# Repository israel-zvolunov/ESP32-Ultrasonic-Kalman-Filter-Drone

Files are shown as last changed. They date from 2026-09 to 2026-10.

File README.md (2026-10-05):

# Drone Altitude Estimation System 🛸
**An Independent Standalone Payload utilizing ESP32 and Linear Kalman Filtering**

Developed as a Final Graduation Project at **Ruppin Academic Center** (2026).
* **Authors:** Netzach Israel Zvolunov & Avishag Avraham
* **Advisor:** Mr. Uzi Chester

---

## 📌 Project Overview
This project presents a standalone, independent payload module designed for real-time quadcopter altitude tracking and safety alerts. To overcome the high-noise environment caused by mechanical vibrations and propeller downwash, the system implements a **Linear Kalman Filter (LKF)** modeled on Constant Velocity (CV) kinematics. 

The system reads dynamic time-of-flight measurements from an ultrasonic sensor (HC-SR04), compensates for mechanical ring-up time biases through linear interpolation calibration, and uses a VCSEL-based laser LiDAR (TF-Luna) as a temporary practical ground truth reference for performance evaluation.

## 🛠️ Key Features
* **Dual-Core Processing:** Implemented in C++ on an ESP32 MCU using FreeRTOS to decouple time-critical sensor sampling from Wi-Fi UDP telemetry transmission.
* **Robust Noise Rejection:** Real-time 30Hz Kalman filtering capable of ignoring sensor time-outs and extreme outliers.
* **Physics-Based Simulation & Telemetry:** Comprehensive MATLAB FDTD wave propagation modeling alongside a real-time UDP Ground Station tracking tool.
* **Hardware Alert System:** Local GPIO-driven physical red LED warning when dropping below a defined safety threshold (1.0m).

---

## 📐 System Architecture
Here is the systemic breakdown of information and electrical distribution paths:

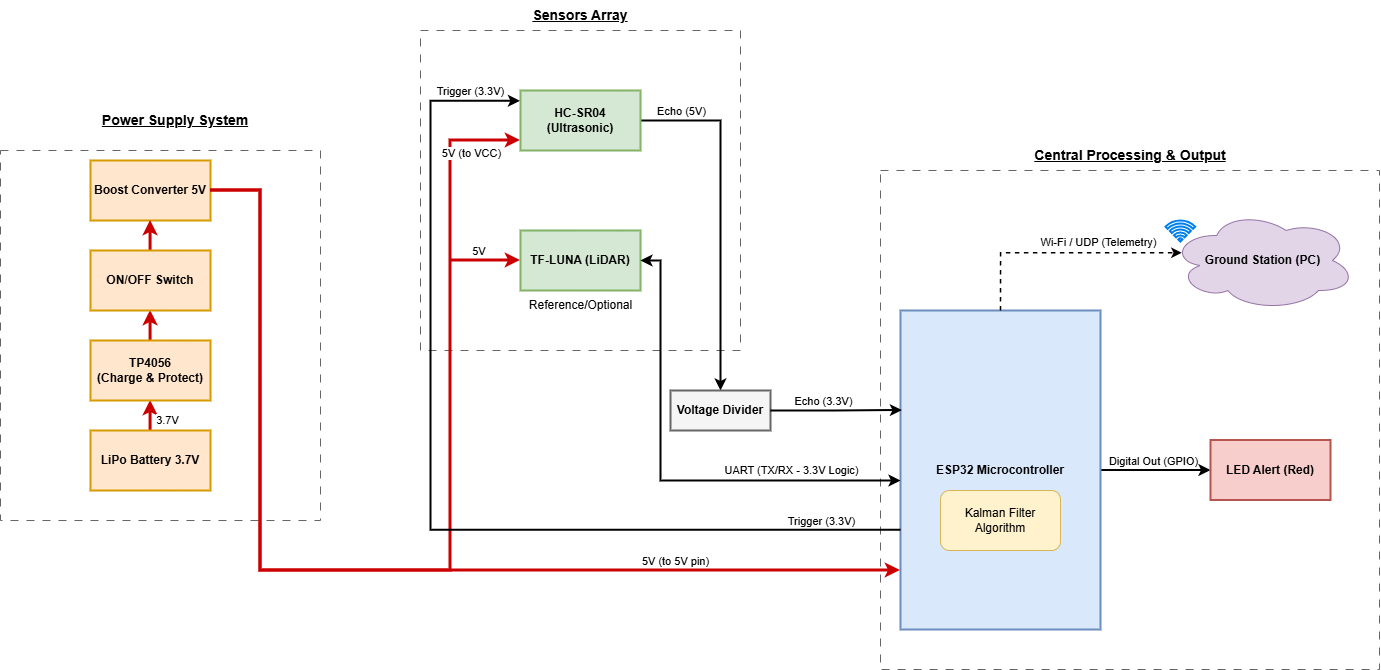
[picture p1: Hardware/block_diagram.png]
System Block Diagram


---

## 🔌 Hardware Wiring Diagram
The following layout represents the practical hardware integration, showcasing the custom independent power grid (LiPo 3.7V to 5V Boost) and the mcu protection voltage divider:

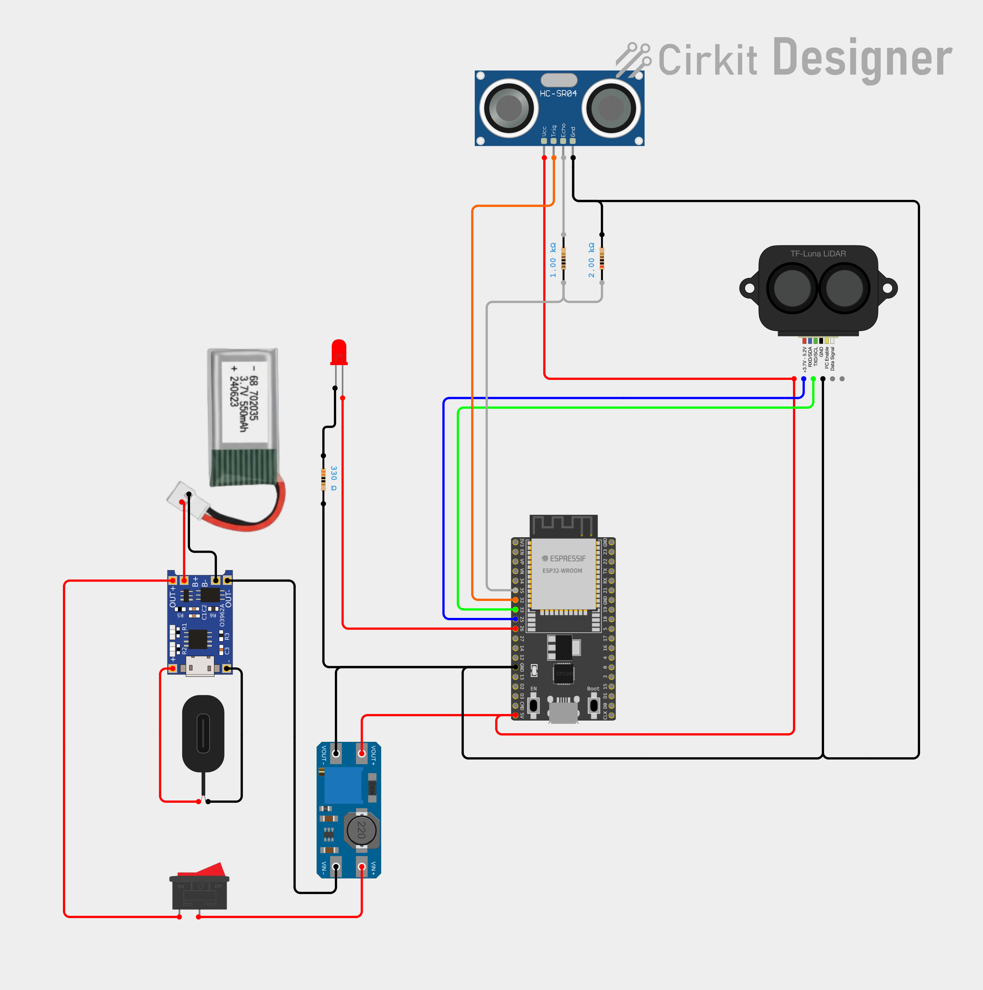
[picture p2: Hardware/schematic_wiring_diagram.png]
System Wiring Diagram


---

## 📐 Enclosure & Drone Integration
Custom standalone enclosure designed in Fusion 360 to securely house the payload components underneath the F450 quadcopter chassis while maintaining its center of gravity:

| 3D Enclosure View | Integrated Drone Payload |
| --- | --- |
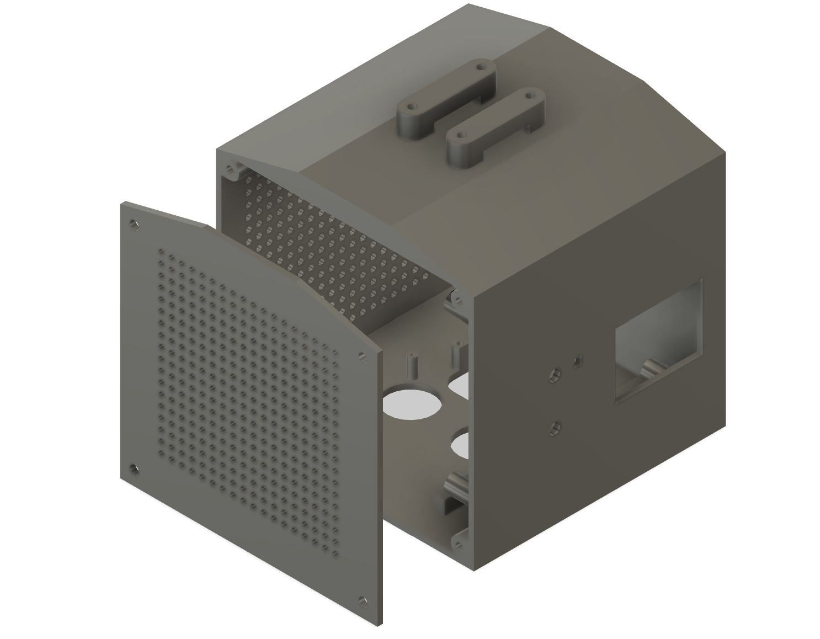
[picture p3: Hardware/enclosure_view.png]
Custom 3D-Printed Enclosure
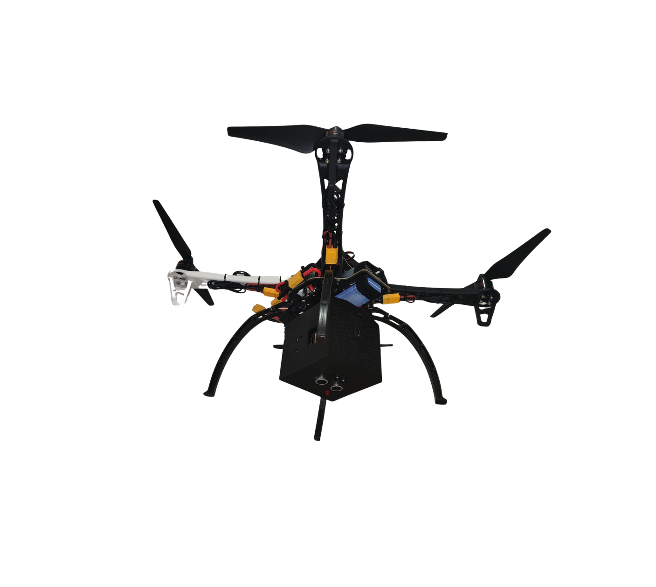
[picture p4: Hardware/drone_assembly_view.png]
Drone Assembly View
|  |  |

---

## 📁 Repository Directory Structure
* `/Firmware` : Contains the production C++ code (`esp32_ultrasonic_kalman_telemetry.ino`) for the ESP32 microcontroller, utilizing hardware interrupts and non-blocking timers.
* `/Simulation` : Complete MATLAB physics and mathematical modeling files:
  * `acoustic_wave_fdtd_simulation.m` — 1D FDTD acoustic propagation.
  * `kalman_filter_model_comparison_gui_exported.m` — Object-Oriented MATLAB App Designer dashboard comparing CV and CA models.
  * `kalman_filter_model_comparison_gui.mlapp` — App Designer binary file for direct layout editing in MATLAB.
* `/GroundStation` : Live diagnostic and telemetry tools running on the ground PC:
  * `ground_station_telemetry_dashboard.m` — Real-time 30Hz UDP telemetry receiver and absolute error plotter.
* `/Hardware` : Contains the Cirkit Designer wiring layout, enclosure image, and production-ready 3D files designed in Fusion 360:
  * `Drone_Box_Body.3mf` — Main chassis.
  * `Drone_Box_Lid.3mf` — Secure interlocking cover.
  * `schematic_wiring_diagram.png` — Real-world wiring schematic.
    * `enclosure_view.png` — Image of the 3D enclosure box.
  * `drone_assembly_view.png` — Photo of the payload integrated onto the F450 drone.

---

## 📊 Quick Start & Telemetry Activation
1. **Hardware Setup:** Connect the HC-SR04 through a 1kΩ/2kΩ voltage divider to GPIO35 (Echo) and GPIO32 (Trigger). Wire the TF-Luna to UART2 (GPIO33/25).
2. **Firmware Deployment:** Flash the ESP32 core via Arduino IDE using the `esp32_ultrasonic_kalman_telemetry.ino` file. Ensure the calibrated measurement noise covariance R = 0.000396 and process noise variance \(\sigma_a^2 = 3.36\) are properly defined in the configuration.
3. **Ground Station Telemetry:** Open MATLAB, run `ground_station_telemetry_dashboard.m` from the `/GroundStation` folder, and connect to the ESP32's local Access Point port via UDP to monitor real-time tracking.

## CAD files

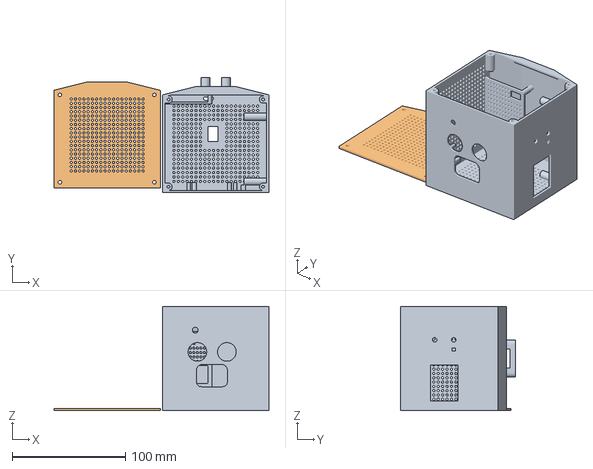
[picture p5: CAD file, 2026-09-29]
Hardware/Drone_Box_Body.3mf
190.0 x 102.0 x 92.0 mm
plastic_box
Drone_Box_Lid

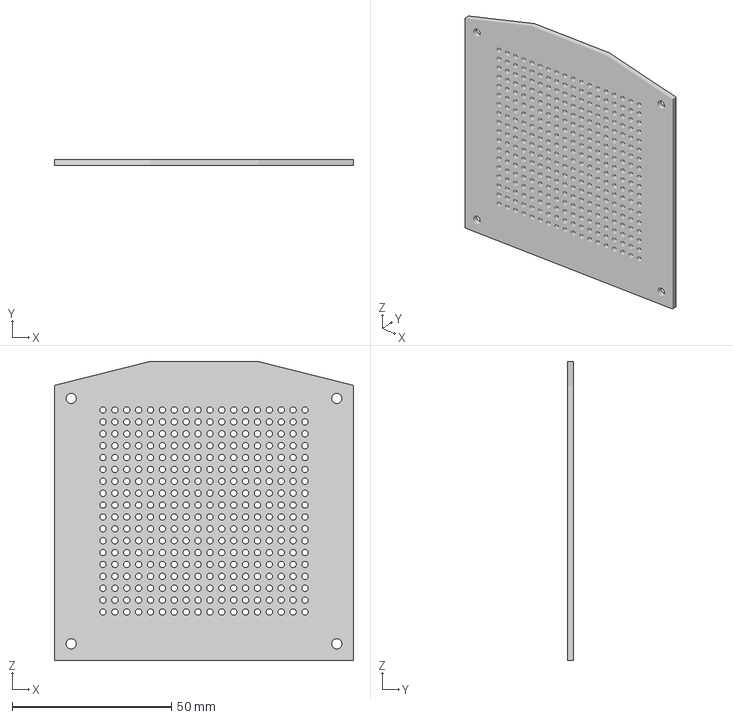
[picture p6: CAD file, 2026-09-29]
Hardware/Drone_Box_Lid.3mf
94.0 x 2.00 x 94.0 mm

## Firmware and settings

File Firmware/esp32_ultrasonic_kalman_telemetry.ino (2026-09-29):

#include <WiFi.h>
#include <WiFiUdp.h>
#include <HardwareSerial.h>

// wifi ap and network settings
const char* ssid = "Project_78_Drone";
const char* password = "12345678"; 

WiFiUDP udp;
const int udpPort = 4210;
IPAddress broadcastIp(192, 168, 4, 255); 

// serial pins for lidar connection
HardwareSerial lidarSerial(2); 
const int RXD2 = 33;
const int TXD2 = 25;
float current_lidar_cm = 0.0;

// mutex vars to share data between core 0 and core 1
SemaphoreHandle_t dataMutex;
float shared_raw_dist = 0.0;
float shared_kalman_dist = 0.0;
float shared_lidar_dist = 0.0; 

// ultrasonic pins and math helper
const int TRIG_PIN = 32;
const int ECHO_PIN = 35;
const float CM_CONVERSION_FACTOR = 57.7; 

// look up tables for dynamic bias fix
const int NUM_CALIBRATION_POINTS = 4;
const float CALIB_DISTANCES[NUM_CALIBRATION_POINTS] = {25.0, 50.0, 100.0, 200.0};
const float CALIB_BIASES[NUM_CALIBRATION_POINTS] = {-1.71,  -0.33,  -2.04,  -0.19};

// linear interpolation for sonar bias compensation
float getDynamicBias(float rawDist) {
  if (rawDist <= CALIB_DISTANCES[0]) return CALIB_BIASES[0];
  if (rawDist >= CALIB_DISTANCES[NUM_CALIBRATION_POINTS - 1]) return CALIB_BIASES[NUM_CALIBRATION_POINTS - 1];
  
  for (int i = 0; i < NUM_CALIBRATION_POINTS - 1; i++) {
    if (rawDist >= CALIB_DISTANCES[i] && rawDist < CALIB_DISTANCES[i+1]) {
      return CALIB_BIASES[i] + ((rawDist - CALIB_DISTANCES[i]) / (CALIB_DISTANCES[i+1] - CALIB_DISTANCES[i])) * (CALIB_BIASES[i+1] - CALIB_BIASES[i]);
    }
  }
  return 0.0; 
}

// linear kalman filter class (constant velocity matrix math)
class KalmanFilterCV {
  private:
    float x_dist; float x_vel;  
    float P00, P01, P10, P11; 
    float R;
    float Q11, Q12, Q21, Q22; 
  public:
    KalmanFilterCV(float initial_distance) {
      x_dist = initial_distance; x_vel = 0.0; 
      P00 = 10.0; P01 = 0.0; P10 = 0.0; P11 = 10.0;
      R = 0.000396; // tuned measurement covariance
    }
    
    void predict(float dt) {
      float sigma_a_sq = 3.36; // process noise variance
      float dt2 = dt * dt;
      float dt3 = dt2 * dt;
      float dt4 = dt3 * dt;
      
      Q11 = sigma_a_sq * (0.25 * dt4);
      Q12 = sigma_a_sq * (0.5 * dt3);
      Q21 = Q12;
      Q22 = sigma_a_sq * dt2;
      
      x_dist = x_dist + x_vel * dt;
      
      P00 = P00 + dt * (P10 + P01) + dt2 * P11 + Q11;
      P01 = P01 + dt * P11 + Q12; 
      P10 = P10 + dt * P11 + Q21; 
      P11 = P11 + Q22;
    }
    
    void update(float z_meas) {
      float S = P00 + R; float K0 = P00 / S; float K1 = P10 / S; 
      float y = z_meas - x_dist;
      x_dist = x_dist + K0 * y; x_vel = x_vel + K1 * y;
      float P00_temp = P00; float P01_temp = P01;
      P00 = (1 - K0) * P00_temp; P01 = (1 - K0) * P01_temp;
      P10 = -K1 * P00_temp + P10; P11 = -K1 * P01_temp + P11;
    }
    float getDistance() { return x_dist; }
};

KalmanFilterCV kf(0.0);

// isr variables for non blocking echo pulse timing
volatile unsigned long echoStart = 0;
volatile unsigned long echoEnd = 0;
volatile bool newMeasurement = false;
unsigned long lastUpdateTime = 0;
unsigned long lastTime = 0;

// hardware interrupt function on echo pin state change
void IRAM_ATTR echoISR() {
  if (digitalRead(ECHO_PIN) == HIGH) {
    echoStart = micros();
  } else {
    echoEnd = micros();
    newMeasurement = true;
  }
}

// ==============================================================================
// CORE 0: Telemetry Task (WiFi & UDP)
// ==============================================================================
void WiFiTask(void *pvParameters) {
  vTaskDelay(1000 / portTICK_PERIOD_MS);
  WiFi.mode(WIFI_AP);
  WiFi.setSleep(false);
  WiFi.softAP(ssid, password, 6, 0, 1); 
  udp.begin(udpPort);
  char packetBuffer[60]; 

  for(;;) {
    // secure shared variables reading
    xSemaphoreTake(dataMutex, portMAX_DELAY);
    float currentRaw = shared_raw_dist;
    float currentKalman = shared_kalman_dist;
    float currentLidar = shared_lidar_dist; 
    xSemaphoreGive(dataMutex);
    
    // pack string payload with tabs and broadcast
    sprintf(packetBuffer, "%.2f\t%.2f\t%.2f", currentRaw, currentKalman, currentLidar);
    udp.beginPacket(broadcastIp, udpPort);
    udp.print(packetBuffer);
    udp.endPacket();
    vTaskDelay(33 / portTICK_PERIOD_MS); // maintain 30hz transmission loop
  }
}

// ==============================================================================
// SETUP
// ==============================================================================
void setup() {
  Serial.begin(115200);
  lidarSerial.begin(115200, SERIAL_8N1, RXD2, TXD2); // tf-luna default uart configuration
  pinMode(TRIG_PIN, OUTPUT);
  pinMode(ECHO_PIN, INPUT);
  dataMutex = xSemaphoreCreateMutex();
  xTaskCreatePinnedToCore(WiFiTask, "WiFiTask", 10000, NULL, 1, NULL, 0); // pin telemetry to core 0
  attachInterrupt(digitalPinToInterrupt(ECHO_PIN), echoISR, CHANGE);
  lastTime = millis();
  lastUpdateTime = millis();
  pinMode(26, OUTPUT); // physical warning led output
}

// ==============================================================================
// CORE 1: Main Loop (Sensors & Math)
// ==============================================================================
void loop() {
  static TickType_t xLastWakeTime = xTaskGetTickCount();
  const TickType_t xFrequency = 33 / portTICK_PERIOD_MS; // target 30hz execution

  // parse 9 byte data packets from lidar serial buffer
  while (lidarSerial.available() >= 9) {
    if (lidarSerial.read() == 0x59) {
      if (lidarSerial.peek() == 0x59) {
        uint8_t frame[9]; frame[0] = 0x59; frame[1] = lidarSerial.read(); 
        uint16_t checksum = frame[0] + frame[1];
        for(int i = 2; i < 9; i++) {
          frame[i] = lidarSerial.read();
          if (i < 8) checksum += frame[i];
        }
        if (frame[8] == (checksum & 0xFF)) {
          current_lidar_cm = frame[2] + (frame[3] << 8); // merge bytes for true distance
        }
      }
    }
  }

  // prediction cycle tracking
  unsigned long currentTime = millis();
  float dt_predict = (currentTime - lastTime) / 1000.0;
  lastTime = currentTime;

  kf.predict(dt_predict);

  unsigned long currentPulseWidth = 0; 
  float correctedDistCm = 0.0;
  bool isMeasurementValid = false;

  // handle completed sonar pulse readings
  if (newMeasurement) {
    currentPulseWidth = echoEnd - echoStart;
    newMeasurement = false; 

    // software threshold timeout protection filter
    if (currentPulseWidth < 30000 && currentPulseWidth > 100) { 
      float rawDistCm = currentPulseWidth / CM_CONVERSION_FACTOR; 
      float currentBias = getDynamicBias(rawDistCm);
      correctedDistCm = rawDistCm - currentBias; // drop fixed bias error
      
      float dt_update = (currentTime - lastUpdateTime) / 1000.0;
      lastUpdateTime = currentTime; 
      
      kf.update(correctedDistCm); // fix kalman matrices state
      isMeasurementValid = true;
    }
  }

  float kalmanDistCm = kf.getDistance();

  // physical led warning logic (trigger under 1 meter safety mark)
  if (kalmanDistCm < 100.0) {
    digitalWrite(26, HIGH);
  } else {
    digitalWrite(26, LOW);
  }
  
  // write state data to global vars using data mutex
  if(xSemaphoreTake(dataMutex, 0) == pdTRUE) {
    shared_raw_dist = isMeasurementValid ? correctedDistCm : ((float)currentPulseWidth / CM_CONVERSION_FACTOR); 
    shared_kalman_dist = kalmanDistCm; 
    shared_lidar_dist = current_lidar_cm;
    xSemaphoreGive(dataMutex);
  }

  // launch new pulse only if echo pin cleared to low state
  if (digitalRead(ECHO_PIN) == LOW) {
    digitalWrite(TRIG_PIN, LOW); delayMicroseconds(2);
    digitalWrite(TRIG_PIN, HIGH); delayMicroseconds(10);
    digitalWrite(TRIG_PIN, LOW);
  }
  
  vTaskDelayUntil(&xLastWakeTime, xFrequency); // sleep until next execution frame
}
